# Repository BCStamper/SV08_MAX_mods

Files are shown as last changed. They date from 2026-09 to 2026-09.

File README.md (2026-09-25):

# Yavoth Demon Remix, remixed SV08 MAX mounts 
See STEP files for modified BTT Eddy Duo mount and modified toolhead mount, modified to allow mounting between the stock belt clamps on the stock Sovol mounting bracket.
**Major differences between this version and the Demon Remix:**
  - Mount fits directly to the carriage block through the stock Sovol toolhead mounting bracket that also retains the ends of the belts.
     - In order to achieve this you must remove the 4 short bolts holding the stock mounting bracket and install the modified Yavoth toolhead mount with longer bolts that go through both the modified mount and the stock toolhead mounting bracket to screw into the carriage block. 
## Build notes for SV08 MAX mount through stock mounting bracket.

This new geometry changes assembly order, but fits together very nicely. 
Parts were printed in Sunlu EasyABS (mounts) and generic ASA (housing) with clear PETG for the LED holders. Parts were printed on my evil Bambu X1C, which I hate to love.
  - There is one bolt in the modified mount that goes the other way, screwing into the toolhead, and it must be installed before the modified mount can be bolted to the carriage.
     - This is because once the modified mount it installed, you still need to turn that bolt into the nut in the toolhead from the back and there’s just enough clearance over the stock mounting bracket to get a hex wrench in there, but not enough clearance to put the bolt in from the back. Learned this twice…
  - Eddy Duo must be mounted on the hotend side of the Eddy mount, with the Eddy Duo toolboard side away from the hotend. Tight cable work, but you gotta run the wiring back towards the hotend between the top of the Eddy Duo and the bottom of the mount, then straight up and over, otherwise it will get pinched between the modified mount and the stock toolhead mounting bracket. There’s just enough clearance.           - Also, I flashed Katapult with a boot loader offset to my Eddy Duo so that I could reflash over CAN if I ever need to, since it’s so tight in there and it’s a pain to get off if you have to flash it over USB. Try to mount the Eddy Duo between 2 and 3mm above the nozzle. Use Loctite. Learned this twice…
  - You will need some pretty long bolts to get all the way through the toolhead and modified mount to screw into the stock toolhead bracket, which is threaded.
     - M3, but I don’t remember exactly how long, maybe 30mm. Use Loctite, and don’t forget to thread the bolt that you placed in the back of the modified mount into the nut that's placed in the toolhead shroud!
  - Finally, and maybe most importantly, you will need shorter threaded standoffs than those that were included with the EBB36 (or was it the Orbiter? I can’t remember, so much hardware)
      - This remix puts the toolhead closer to the carriage block, and that means the toolhead board (mounted behind the extruder) hangs out far enough that the wiring will almost certainly collide with the big wiring harness/PTFE tube support bracket thingy bolted to the gantry of the SV08 MAX. I only had to learn this once, but I learned it the hard way. 
      - I didn’t have much of a selection of PCB standoffs in my stash so I ended up cutting a 20mm standoff down to about 13mm with a rotary tool and that gave me just enough clearance, but it definitely tightens the gap between the back of the extruder stepper and the toolhead board. I’ve been keeping an eye on the temps to make sure that smaller clearance doesn’t cause overheating issues. So far so good and I’ve probably put 100 or so hours on this new toolhead.
  - I also installed the O2 Orbiter Filament Sensor (designed by Robert Lorincz) since I’m not currently using the filament buffer (thanks Mainline) and would otherwise have no runout sensor. This filament sensor is worth every penny and I love it.
Do a full calibration, including Eddy temperature drift calibration. Don’t skip input shaper!
## Some advantages of this setup for SV08 MAX:
** Nozzle is in exactly the same physical position as stock toolhead with regards to carriage block, so no need to change that offset. You will need to change the Eddy offset, which is something like X=0, Y=26.72
** X-endstop switch is in exactly the same physical position as stock toolhead, and will contact the end stop trigger tab on the gantry perfectly. I used the standard Omron [D2F-5?] held on with just nuts and bolts. 
** You don’t have to buy another set of longer belts to use this toolhead! Which means you also don’t have to go through the tedious process of tensioning them. You can swap the stock toolhead back in without having to mess with the belts at all, just make sure you keep the shorter bolts that went through the stock mounting bracket.

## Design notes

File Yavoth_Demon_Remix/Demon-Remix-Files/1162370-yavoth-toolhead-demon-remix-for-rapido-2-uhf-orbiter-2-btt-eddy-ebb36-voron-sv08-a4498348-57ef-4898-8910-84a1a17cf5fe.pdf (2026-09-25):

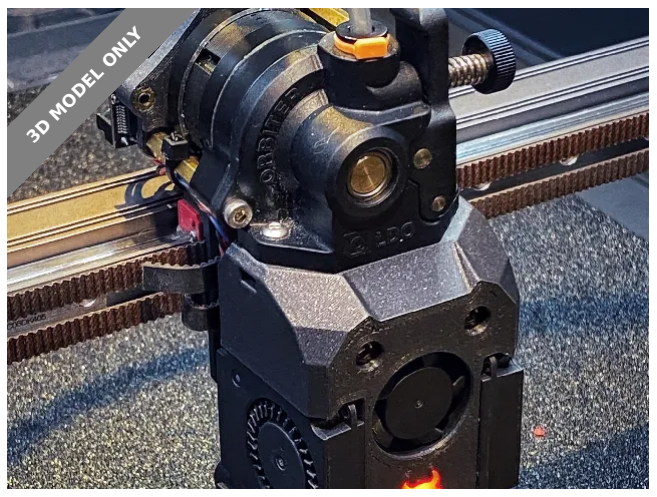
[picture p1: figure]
3D MODEL ONLY

## Summary

Remixed files to suit the listed components!

3D Printers (https://printables.com/model?categoryId=1) > Voron Parts & Upgrades (https://printables.com/model?categoryId=137)

Please be sure to hit the like button as this really helps me out here! Also be sure to post a make too! Would love to see your prints & installs! Here's my remix of these awesome files from chirpy2605 to bring them all together in this easy to print & assemble version for the listed components, other parts may fit but are untested!

Added second “status” NeoPixel LED as original doesn't have one! It only has one nozzle led. Also made a few visual tweaks.

Plus included is one of my favourite EBB36 mounts from Armchairt-Heavy-Industries remixed to fit here.

The printing, fit & assembly MUST BE PRECISE & EXACT!! Everything does fit, & works if printed on a well tuned & setup machine!

3DPrintDemon (https://printables.com/@3DPrintDemon)

## Yavoth Toolhead Demon Remix For

Rapido 2 UHF,

## Orbiter 2, BTT

Eddy, EBB36,

## Voron, SV08

VIEW IN BROWSER (https://printables.com/model/1162370-yavoth-toolhead-demon-remix-for-rapido-2-uhf-orbit)

updated 11. 12. 2025 | published 11. 12. 2025

DO NOT LEAVE A BAD REVEIW BECAUSE YOU HAD A BAD PRINT OR COULDN'T GET SOMETHING TO FIT! It clearly does fit & does work!

If you have an issue, make a comment or send a pm, not just leave low stars as that's not cool.
BOM

x1 bottle blue thread lock!!!

x1 Rapido 2 UHF Plus (or Rapido 2F!)

x1 Orbiter v2.0 or v2.5!

x1 BTT EEB36 toolhead board.

x1 BTT Eddy Probe - version your choice.

x2 GDSTime 4010 blowers - DO NOT CHEAP OUT on Amazon specials! Don't be that guy!

x1 Honeybadger or GDSTime 2510 Hotend axial fan.

x2 NeoPixel 10mm GRBW LED's.

x1 short length Capricorn PTFE tube, cut to length.

x7 Voron BOM M3 heat inserts

x5 DIN 562 M3 Square nuts.

x2 M3 40mm SHCS

x5 M3 8mm SHCS

x8 M3 10mm SHCS

x2 M3 10mm BHCS

x1 M3 12mm BHCS

x2 M3 washers

Also print a couple of these! (https://github.com/chirpy2605/voron/blob/main/general/Alternative_Voron_Mounts/Modified_Mounts/V1_V2/STLs/MGN12H/Probe_Bracket.stl)

They’re used to attach the Eddy probe.
PRINTING

Use Voron BOM settings for ABS/ASA for main parts. Print parts with included support pieces face down!

•
•

Clear PETG for LED Holder!!!
Print on shortest flat closed side! Use tree supports in the open side.

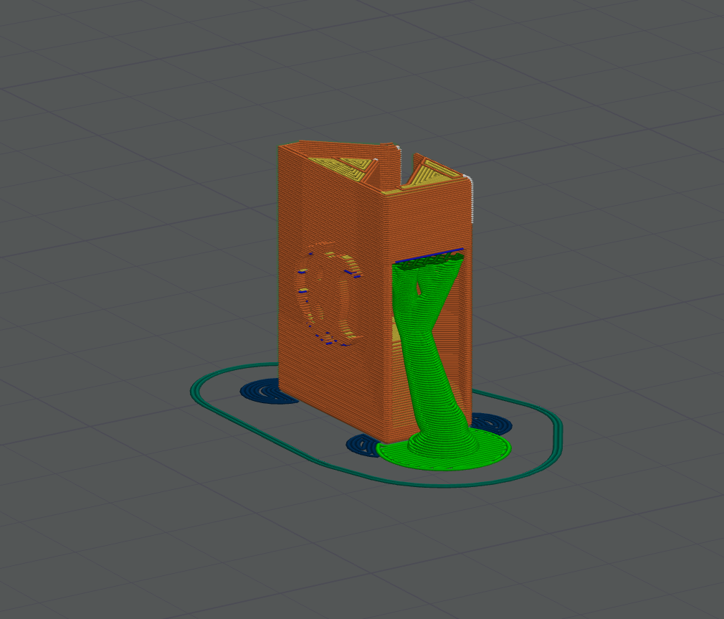
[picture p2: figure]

CONSTRUCTION

Follow the images & text below.....

THREAD LOCK ALL BOLTS!

Add x2 heat inserts

•
•

•

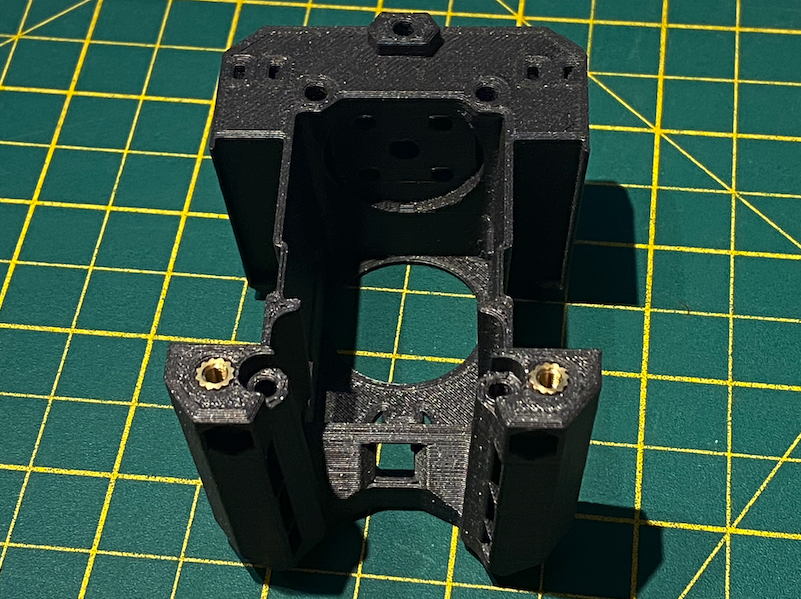
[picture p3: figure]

Add x3 heat inserts & bolts. x3 M3 8mm SHCS top & bottom, x2 M3 10mm SHCS middle, x1 M3 12mm BHCS top.

•

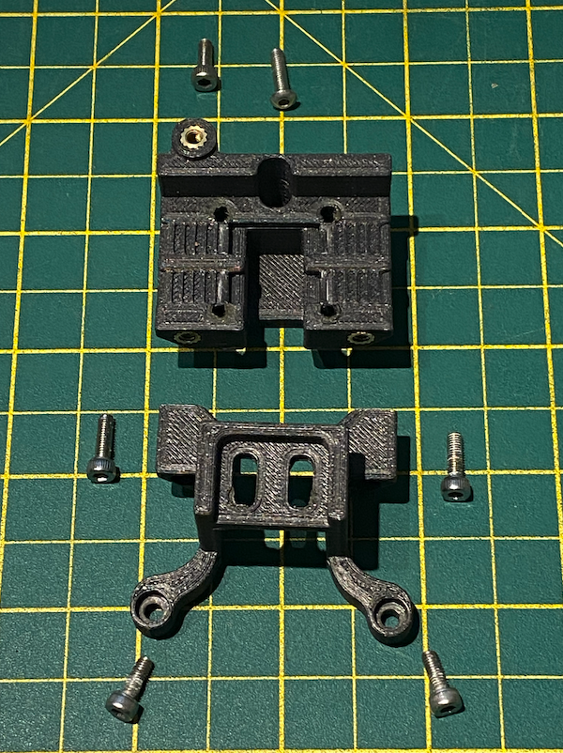
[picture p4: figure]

- Add heat inserts

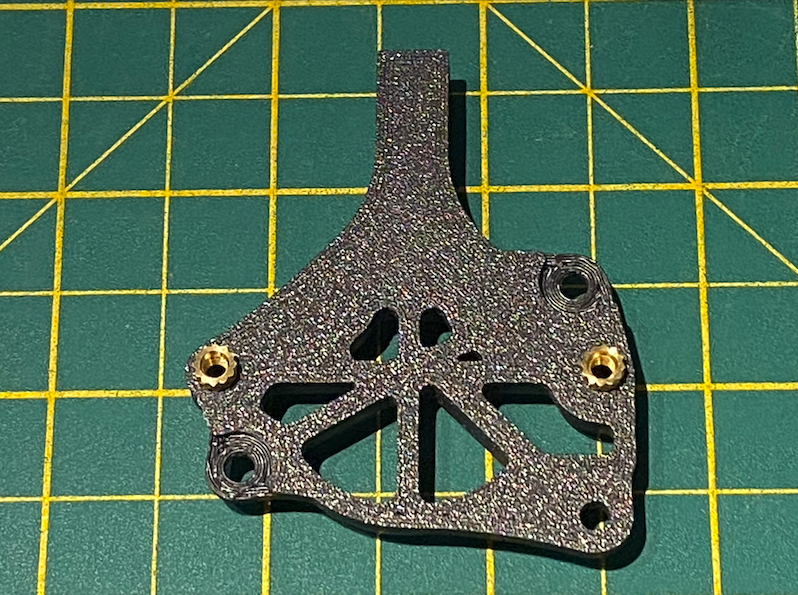
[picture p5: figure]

- Bolts x3 M3 8mm SHCS top & bottom, x2 M3 10mm SHCS middle.

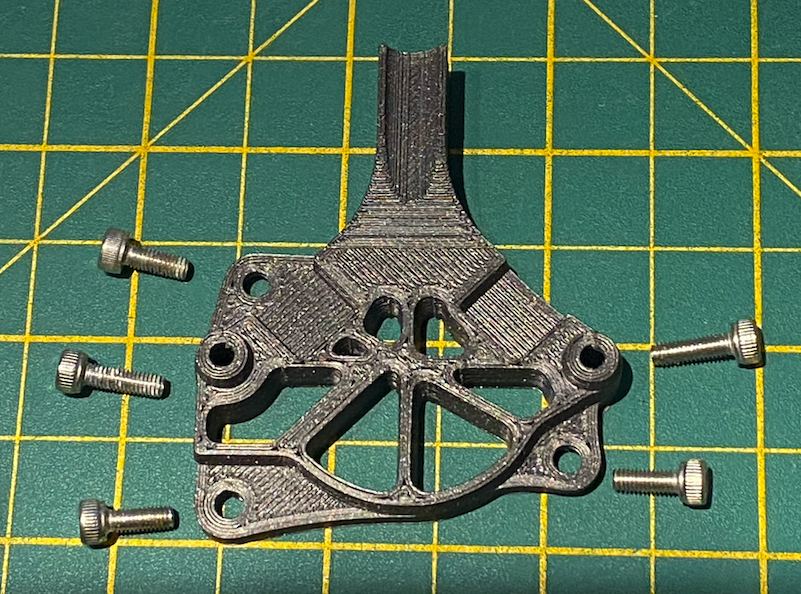
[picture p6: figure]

Insert your NeoPixels like this, BE CAREFUL! Don't break them, use very thin wire (1mm silicone wire!) & make sure your soldering is good & compact OR THEY WILL NOT FIT!!! Also be sure to get the orientation correct!! You don't want to have to change this after it's built!
TEST LEDs BEFORE ASSEMBLY!!!

•

•

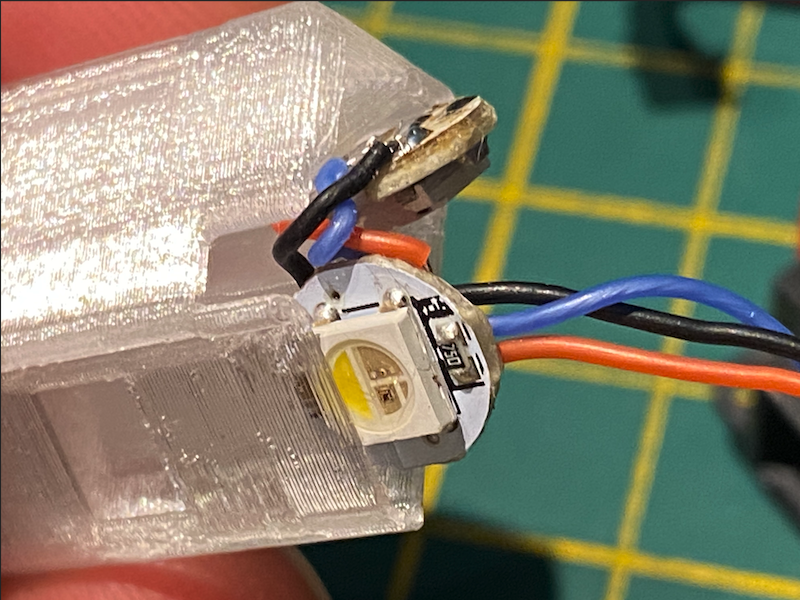
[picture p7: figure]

- Feed 2510 fan wires through the top!

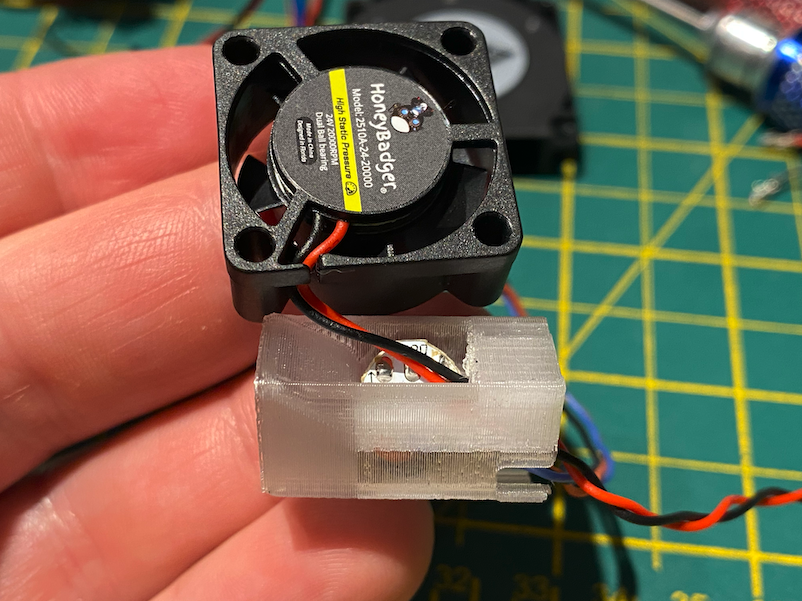
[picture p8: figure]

Insert into main body feeding wires out the right side as you do. Make sure the little demon face pops into the cutout correctly & evenly. Your prints must be good or this will not fit!

•

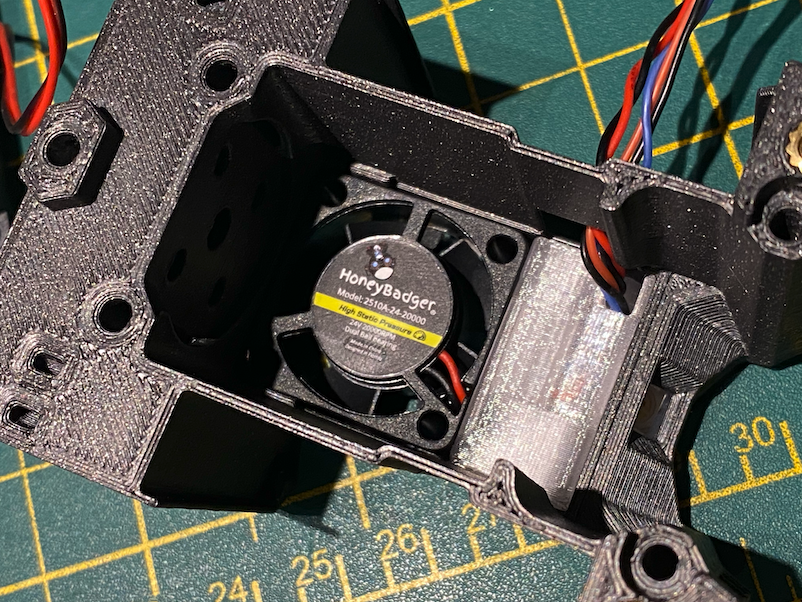
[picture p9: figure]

x3 heat inserts & x2 square nuts. Use dot of super glue to hold in correct position.

•

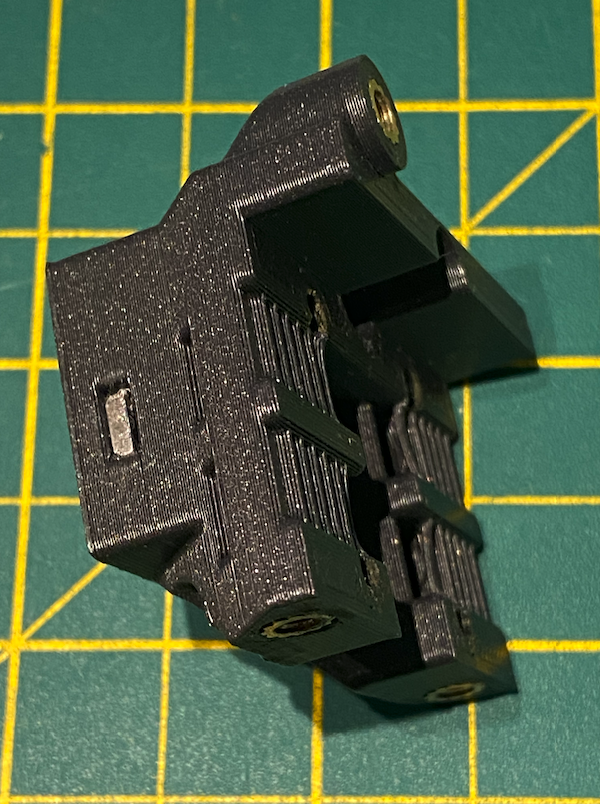
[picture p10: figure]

Use x1 M3 12mm BHCS here because uses smaller size hex wrench! You'll need this!

•

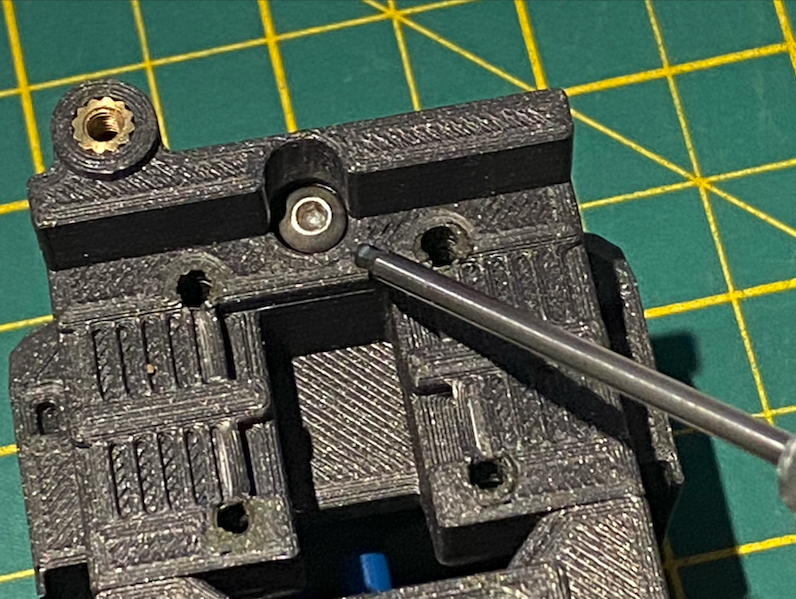
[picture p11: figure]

PTFE tube & x2 M3 10mm BHCS to attach extruder, held by x2 square nuts loaded from sides. Use dot of super glue to hold in correct position.
x2 M3 40mm SHCS in the front there.

•

•

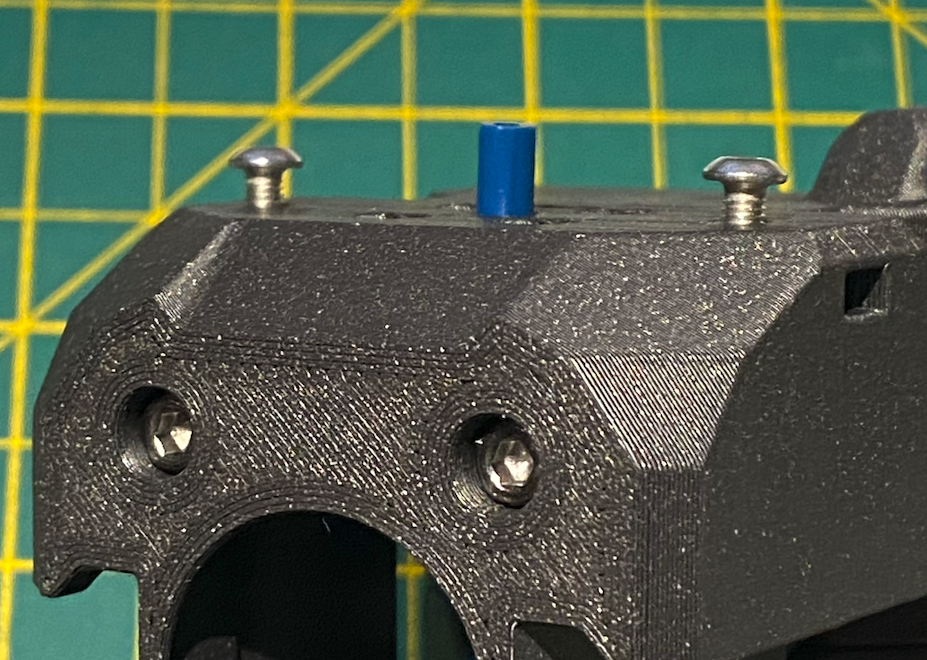
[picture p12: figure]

- See x3 square nuts top centre & sides.

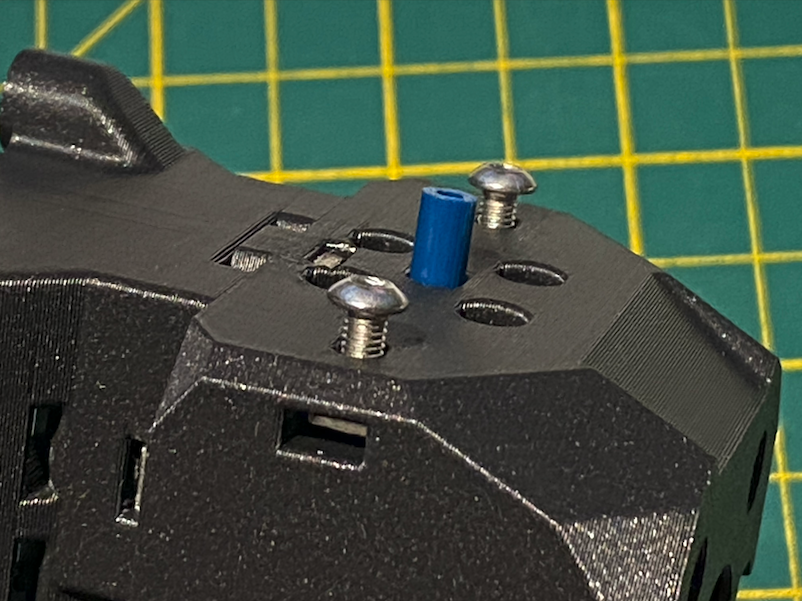
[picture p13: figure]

Make sure your hotend is aligned like this, with the set screw inline with the cables, or this unit will not fit!

•

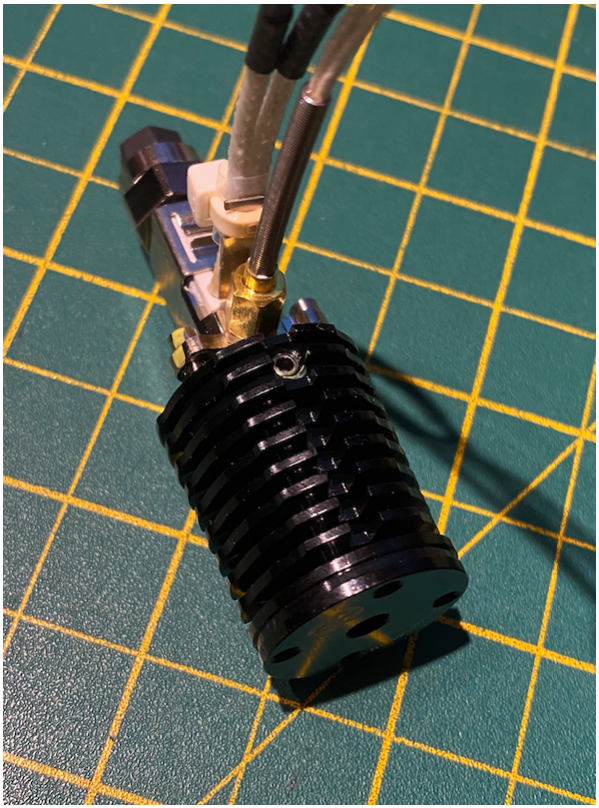
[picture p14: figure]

Slide 4010 fans in from the rear, BE CAREFUL OF WIRES!!! You can break stuff here!!!
Add hotend & secure with wires out the rear right side as per the images below.
Insert PTFE tube.
Add extruder and cut tube to correct length.
Attach toolhead board.

•

•

•
•
•

Tidy up wiring!

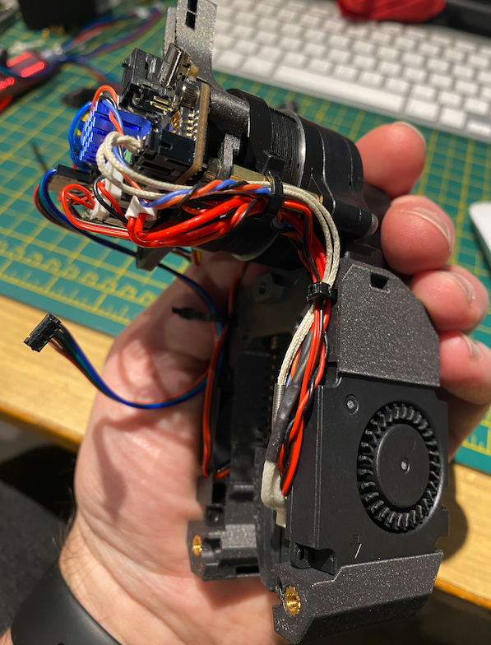
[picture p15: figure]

Add long bolts from Eddy to STL link below & fit THIS WAY ROUND! This is so the probe can be adjusted when attached to the toolhead!! Add x2 M3 washers under bolt heads! IMPORTANT!!

•

•

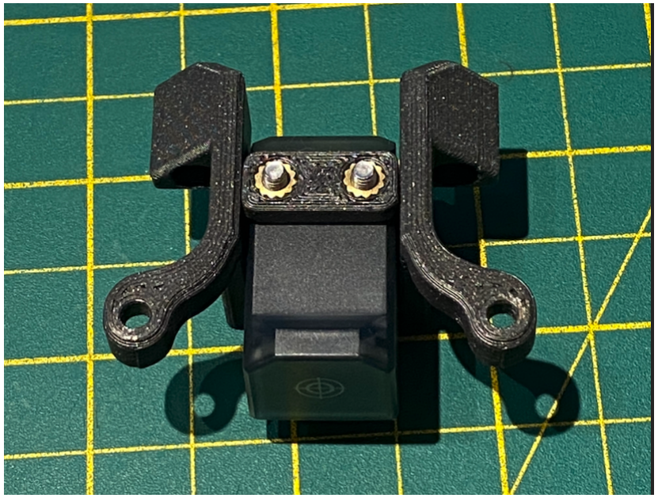
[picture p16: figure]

MOUNTING

Feed belts through slots.
Attach the carriage to the X axis bearing block, MAKE SURE THE M3 12mm BHCS is in place BEFORE you fit this!!!
Set belts evenly!!
Tighten bolts to secure.
Next drop the main assembly onto the carriage. Fix in place with the x2 M3 40mm SHCS. Tighten up the 1x M3 12mm BHCS bolt from the rear of the top of the bearing block. Sliding hex tool into slot.
Now add the Probe mount to the rear & connect everything up!
DO NOT FORGET THIS!!!

You will need to print one of these! For the Eddy probe

https://github.com/chirpy2605/voron/blob/main/general/Alternative_Voron_Mounts/Modified_Mounts/V1_V2/STLs/MGN12H/Probe_Bracket.stl (https://github.com/chirpy2605/voron/blob/main/general/Alternative_Voron_Mounts/Modified_Mounts/V1_V2/STLs/MGN12H/Probe_Bracket.stl)
TOOLHEAD OFFSET

x_offset: 0

•
•

•
•
•

•

y_offset: 25

The printing, fit & assembly MUST BE PRECISE & EXACT!! Everything does fit, & works if printed on a well tuned & setup machine!

DO NOT LEAVE A BAD REVEIW BECAUSE YOU HAD A BAD PRINT OR COULDN'T GET SOMETHING TO FIT! It clearly does fit & does work!

If you have an issue, make a comment or send a pm, not just leave low stars as that's not cool.

## This remix is based on

voron/general/Alternative_Voron_Mounts/ Modified_Mounts/V1_V2/STLs/Carriage_Bases/ Carriage_Base_Long.stl at main · chirpy2605/voron (https://github.com/chirpy2605/voron/blob/main/general/Alternative_Voron_Mounts/Modified_Mounts/V1_V2/STLs/Carriage_Bases/Carriage_Base_Long.stl)

voron/general/Alternative_Voron_Mounts/ Modified_Mounts/V1_V2/STLs/MGN12H/ MGN12H_X_Carriage_Lite.stl at main · chirpy2605/ voron (https://github.com/chirpy2605/voron/blob/main/general/Alternative_Voron_Mounts/Modified_Mounts/V1_V2/STLs/MGN12H/MGN12H_X_Carriage_Lite.stl)

voron/V0/Yavoth/STLs/LED_Holder_UHF.stl at main · chirpy2605/voron (https://github.com/chirpy2605/voron/blob/main/V0/Yavoth/STLs/LED_Holder_UHF.stl)

voron/V0/Yavoth/STLs/Orbiter_v2_Spacing/ Cowl_Dragon_OB2_UHF.stl at main · chirpy2605/voron (https://github.com/chirpy2605/voron/blob/main/V0/Yavoth/STLs/Orbiter_v2_Spacing/Cowl_Dragon_OB2_UHF.stl)

Xol-Toolhead/STL/EBB Mounts/EBB36 Mount -Orbiter2.0 [strain relief].stl at main · Armchair-Heavy-Industries/Xol-Toolhead (https://github.com/Armchair-Heavy-Industries/Xol-Toolhead/blob/main/STL/EBB%20Mounts/EBB36%20Mount%20-%20Orbiter2.0%20%5Bstrain%20relief%5D.stl)

## Model files

- Print ASA/ABS
- Print ASA/ABS
- Print ASA/ABS
- Print ASA/ABS

## License

This work is licensed under a GNU

General Public License v3.0 (https://www.gnu.org/licenses/gpl-3.0.html)

✖ | Sharing without ATTRIBUTION
✔ | Remix Culture allowed
✔ | Commercial Use
✔ | Meets Open Definition
ℹ | Share under the same license

yavoth-demon-v11.stl

yavoth-demon-eddy-mount-v10.stl

yavoth-demon-carriage-v12.stl

demon-yavoth-ledx2-v13.stl

yavothxol-demon-ebb-mount.stl

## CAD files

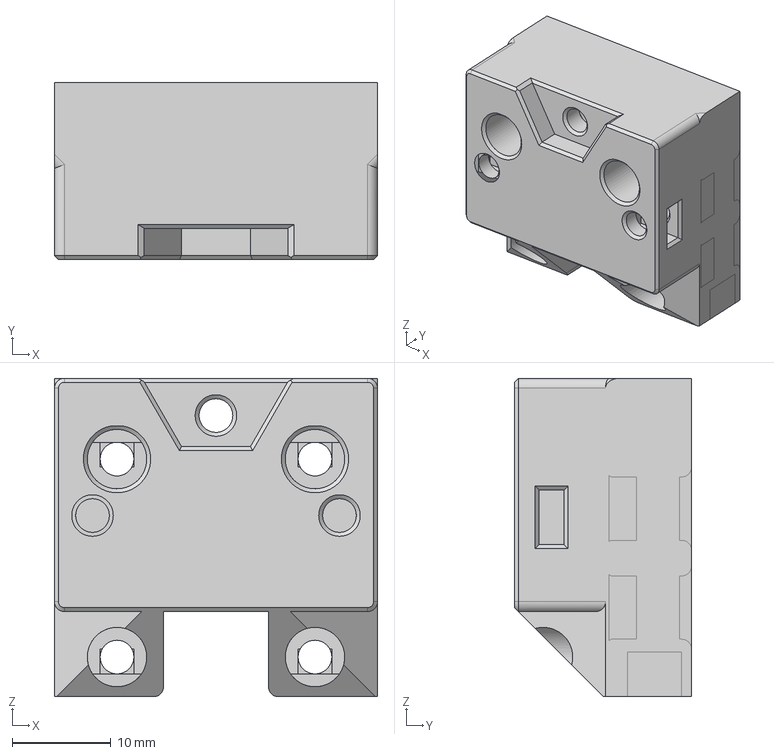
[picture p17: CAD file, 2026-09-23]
mounts/SV08MAX_Belt_Clamp_Mount.step
32.6 x 17.9 x 32.2 mm

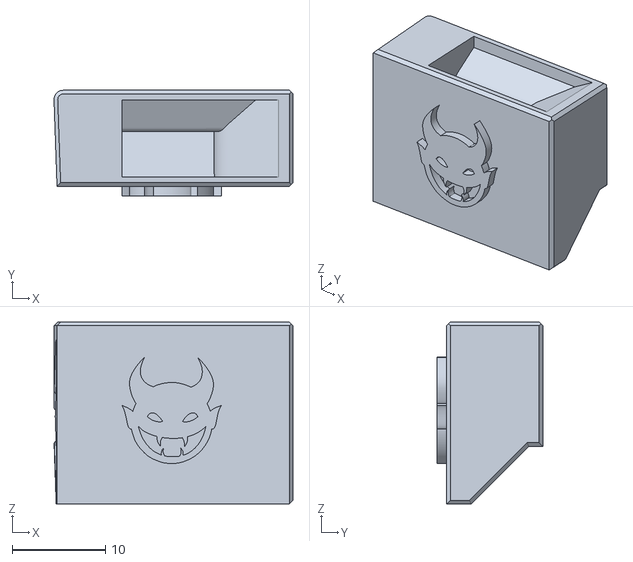
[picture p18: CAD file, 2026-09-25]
Yavoth_Demon_Remix/Demon-Remix-Files/demon-yavoth-ledx2-v13.stl
25.6 x 11.3 x 19.5

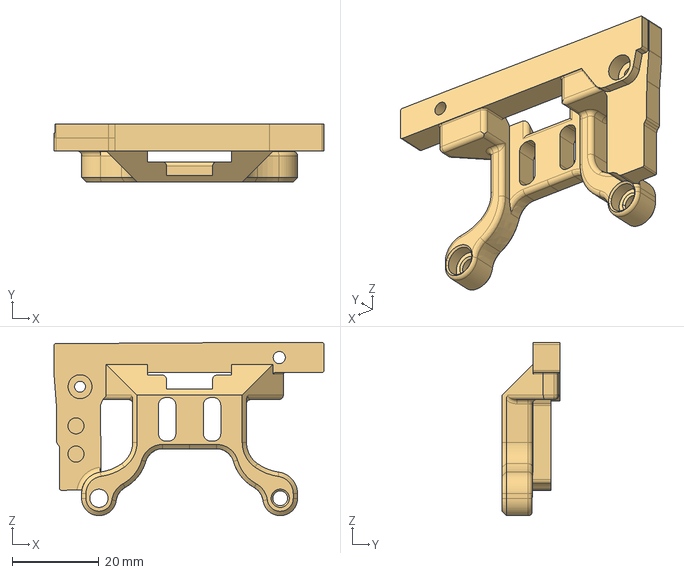
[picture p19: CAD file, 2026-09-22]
mounts/SV08MAX_Eddy_duo_mount_D2F-5.step
62.2 x 13.3 x 39.9 mm

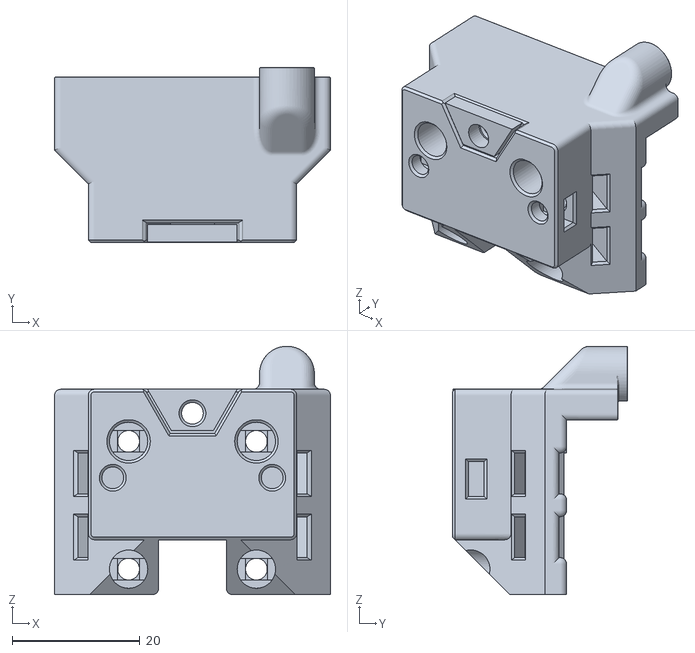
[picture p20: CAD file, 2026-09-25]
Yavoth_Demon_Remix/Demon-Remix-Files/yavoth-demon-carriage-v12.stl
43.2 x 27.5 x 38.9

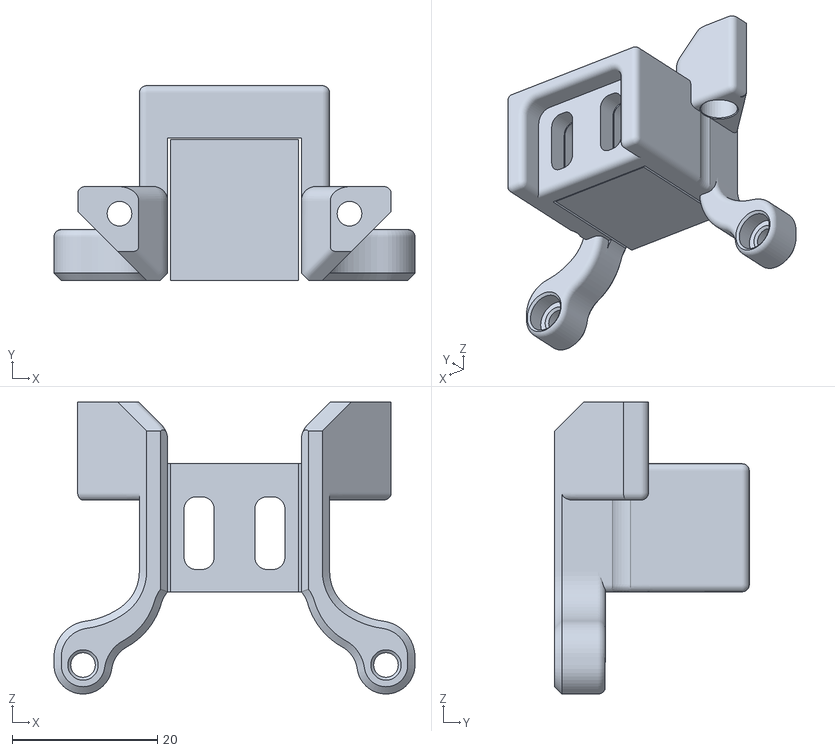
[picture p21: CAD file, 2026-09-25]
Yavoth_Demon_Remix/Demon-Remix-Files/yavoth-demon-eddy-mount-v10.stl
49.8 x 26.8 x 40.2

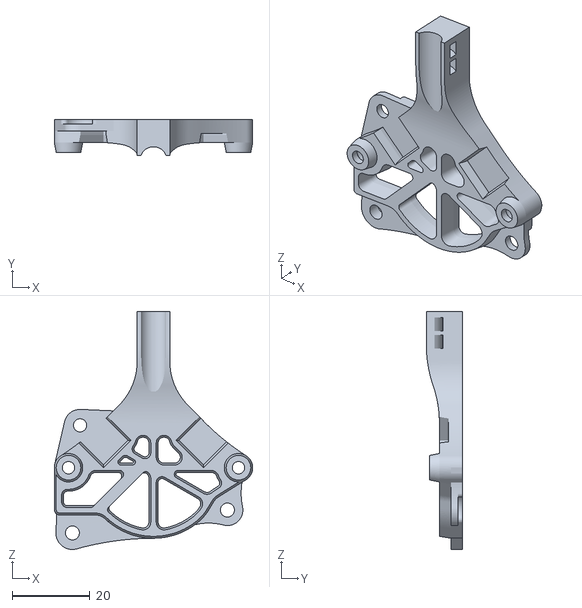
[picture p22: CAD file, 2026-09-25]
Yavoth_Demon_Remix/Demon-Remix-Files/yavothxol-demon-ebb-mount.stl
51.2 x 9.36 x 61.4

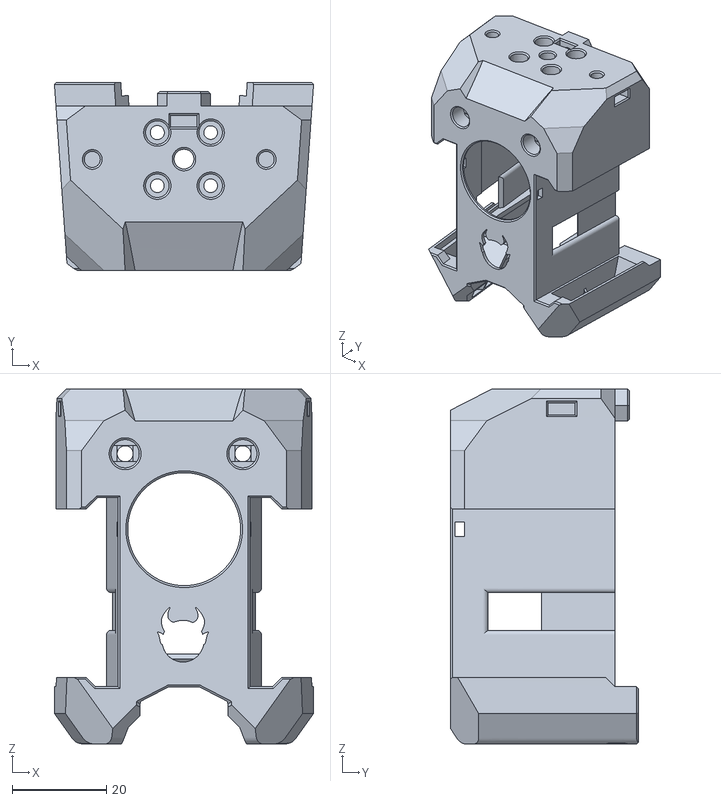
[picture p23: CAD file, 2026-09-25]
Yavoth_Demon_Remix/Demon-Remix-Files/yavoth-demon-v11.stl
55.1 x 40.0 x 75.5

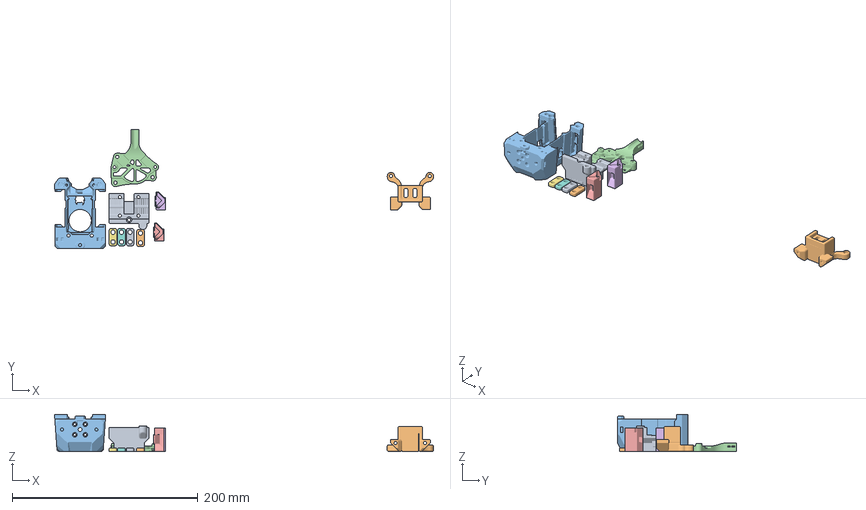
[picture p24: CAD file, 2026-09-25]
Yavoth_Demon_Remix/Demon-Remix-Files/yavoth-demon.3mf
407.7 x 127.7 x 40.0 mm
yavoth-demon-carriage-v12.stl
yavoth-demon-eddy-mount-v10.stl
yavoth-demon-v11.stl
yavothxol-demon-ebb-mount.stl
demon-yavoth-ledx2-v13.stl x 2
Probe_Bracket.stl x 4

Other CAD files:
mounts/SV08MAX_belt_clamp_mount.stl

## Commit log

2026-09-22 Added Yavoth toolhead brackets to repo for sharing
    [SV08MAX_Eddy_duo_mount_D2F-5.step, SV08MAX_belt_clamp_mount.stl]
2026-09-23 Added folder for better organization
    [SV08MAX_Eddy_duo_mount_D2F-5.step, SV08MAX_belt_clamp_mount.stl]
2026-09-23 Added STEP version of SV08MAX_belt_clamp_mount
    [SV08MAX_Belt_Clamp_Mount.step]
2026-09-25 Add README for Yavoth Demon Remix SV08 MAX mounts
    Added first pass instructions and build notes for the Yavoth Demon Remix SV08 MAX mounts, including assembly tips and advantages of the new setup for SV08 MAX specifically. Work in progress, just don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
2026-09-25 Adding original Yavoth Demon Remix files to repo for reference
    [SV08MAX_Eddy_duo_mount_D2F-5.step, SV08MAX_belt_clamp_mount.stl, demon-yavoth-ledx2-v13.stl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]
